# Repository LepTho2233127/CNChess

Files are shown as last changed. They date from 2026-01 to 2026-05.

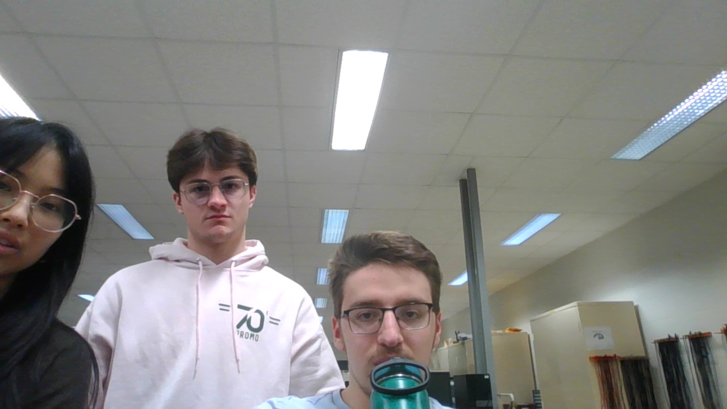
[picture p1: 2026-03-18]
python/best_chess_board.jpg

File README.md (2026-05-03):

# CNChess - Automated Chess System
Automated chess board for playing against chess engine. For more information concerning the hardware needed visit the [wiki](https://github.com/LepTho2233127/CNChess/wiki)
Image (4)

<div align="center">
IMG_8428 (online-video-cutter com) (2)
</div>

## Get Started for Software Development

### 1. Clone project
    git clone <REPO_URL>

### 2. Install Ubuntu WSL (only if on windows)

[Instructions](https://learn.microsoft.com/en-us/windows/wsl/install)

### 3. Open WSL inside project folder

### 4. Install docker

```bash
sudo apt update && sudo apt upgrade
```

[Instructions](https://docs.docker.com/engine/install/ubuntu/)

### 5. If on WSL, give access to USB port to WSL 

```bash
winget install --interactive --exact dorssel.usbipd-win
```

> [!IMPORTANT]
> Run the following commands as admin in PowerShell. You also need to keep a WSL active

```PowerShell
usbipd list
usbipd bind --busid 4-4
usbipd attach --wsl --busid <busid>
```

In WSL, check if you see the device you just attached
```bash
lsusb
```

### 6. Build docker image
```bash
sudo docker compose build
```

### 7. Give docker access to window 
```bash
xhost +local:docker
```

### 8. Run code
```bash
sudo docker compose run cnchess
```

### 9. Close docker (or ctrl-c)
```bash
sudo docker compose down
```
> [!NOTE]
> If you are on a Linux operating systems, it is possible to not use Docker by following this procedure

### 1. Install Stockfish at default location
```bash
sudo apt update
sudo apt install stockfish
which stockfish
```
>[!IMPORTANT]
>If path obtained when running which command is not /usr/games/stockfish, you need to change it in CNChess.py file manually

### 2. Install Python libraries
Inside CNChess directory run : 

```bash
cd python
python -m venv .venv
source .venv/bin/activate
pip install -r requirements.txt
```

### 3. Run the project
With right hardware, run this command in python directory with virtual environment activated
```bash
python main.py
```
If no camera or serial port is detected, you might need to change it respectively inside Cam.py or Communication.py.

## Documentation
Additional software documentation is available and generated using MkDocs [docs](https://leptho2233127.github.io/CNChess/). Run `mkdocs build` inside project directory to build it.
Located inside docs_build directory, open in a browser to access it.

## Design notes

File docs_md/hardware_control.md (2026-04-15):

[← Back to Home](index.md)

# Hardware Control

Robot control systems for movement, positioning, and piece manipulation.

**Related Components:** [Game Engine](game_engine.md) | [Vision System](vision_system.md) | [Communication](communication.md) | [UI](user_interface.md)

## Overview

The Hardware Control component is responsible for:

- **Pathfinding & Trajectory Planning** - Calculate optimal robot paths from as grid coordinates
- **Servo Control** - Manage piece picking and placement

## Key Features

- **Intelligent Pathfinding** - Efficient path calculation avoiding collisions using A* algorithm
- **Servo Management** - Automated piece manipulation with magnet control

## Architecture

```
Hardware Control
├── Pathfinding Engine
│   ├── Start Position
│   ├── Destination Position
│   └── Path Generation
└── Movement Commands
    ├── Grid Positions
    └── Servo Operations
```

## Coordinate Systems

### Chess Board Coordinates
- Columns: A-H (Left to Right)
- Rows: 1-8 (Bottom to Top)
- Example: e4 (King's Pawn opening)

### Grid Coordinates
- Grid double the size of chess board (16x16), so the pieces can be moved in between the squares. (0,0) represents the bottom left corner
- Calibration required to the bottom left corner for accurate mapping

## Usage Example

```python
from Control import Control
import chess

# Initialize control system
control = Control()

# Home the robot
control.go_home()

# Get path for a move
move = chess.Move.from_uci('e2e4')
path = control.get_path(move, board_state)
```

## Module Documentation

### Control Module

The core control system for robot movement and pathfinding.

::: Control
    options:
      docstring_style: google

```

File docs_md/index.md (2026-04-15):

# CNChess Documentation

Welcome to the CNChess documentation! This is an automated chess playing robot that uses computer vision and robotic control to play chess games.

## System Overview

The CNChess system is divided into five main component groups. Each component has its own dedicated documentation page:

### [Game Engine](game_engine.md)
Chess logic and chess engine decision-making. Handles game state, move validation, and opponent strategy.

### [Hardware Control](hardware_control.md)
Robot movement and positioning system. Controls gantry movements, servo operations, and trajectory planning.

### [Vision System](vision_system.md)
Computer vision for board detection. Processes camera input to recognize piece positions and moves.

### [Communication Layer](communication.md)
Device communication protocol. Manages serial communication with ESP32 and hardware control.

### [User Interface](user_interface.md)
PyQt6-based graphical interface. Provides game interaction, settings configuration, and visual feedback.

## System Architecture

```
User Input (Button Press)
    ↓
Camera (Detect Result)
    ↓
Game Engine (Validate Move and Calculates Computer Move)
    ↓
Control Module (Path Planning)
    ↓
Communication (Send to Device)
    ↓
Hardware (Robot Movement)
    ↓
Update Game State (UI Display)
```

## Quick start

### 1. Clone project
    git clone <REPO_URL>

### 2. Install Ubuntu WSL (only if on windows)

[Instructions](https://learn.microsoft.com/en-us/windows/wsl/install)

### 3. Open WSL inside project folder

### 4. Install docker

```bash
sudo apt update && sudo apt upgrade
```

[Instructions](https://docs.docker.com/engine/install/ubuntu/)

### 5. If on WSL, give access to USB port to WSL 

```bash
winget install --interactive --exact dorssel.usbipd-win
```

> [!IMPORTANT]
> Run the following commands as admin in PowerShell. You also need to keep a WSL active

```PowerShell
usbipd list
usbipd bind --busid 4-4
usbipd attach --wsl --busid <busid>
```

In WSL, check if you see the device you just attached
```bash
lsusb
```

### 6. Build docker image
```bash
sudo docker compose build
```

### 7. Give docker access to window 
```bash
xhost +local:docker
```

### 8. Run code
```bash
sudo docker compose run cnchess
```

### 9. Close docker (or ctrl-c)
```bash
sudo docker compose down
```
> [!NOTE]
> If you are on a Linux operating systems, it is possible to not use Docker by following this procedure

### 1. Install Stockfish at default location
```bash
sudo apt update
sudo apt install stockfish
which stockfish
```
>[!IMPORTANT]
>If path obtained when running which command is not /usr/games/stockfish, you need to change it in CNChess.py file manually

### 2. Install Python libraries
Inside CNChess directory run : 

```bash
cd python
python -m venv .venv
source .venv/bin/activate
pip install -r requirements.txt
```

### 3. Run the project
With right hardware, run this command in python directory with virtual environment activated
```bash
python main.py
```
If no camera or serial port is detected, you might need to change it respectively inside Cam.py or Communication.py.

## Documentation
Additional software documentation is available and generated using MkDocs. Run `mkdocs build` inside project directory to build it.
Located inside docs directory, open in a browser to access it.

## System Requirements

- Docker or Python>=3.8
- PyQt6
- OpenCV for vision processing
- PySerial for device communication
- Python chess library for game logic
- Stockfish 14.1 (bundled inside docker)

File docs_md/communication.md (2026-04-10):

[← Back to Home](index.md)

# Communication Layer

Device communication for ESP32 and hardware control via PySerial.

**Related Components:** [Game Engine](game_engine.md) | [Hardware Control](hardware_control.md) | [Vision System](vision_system.md) | [UI](user_interface.md)

## Overview

The Communication Layer component is responsible for:

- **Serial Communication** - Establish connection with microcontroller
- **Protocol Handling** - Encode/decode command messages
- **Command Transmission** - Send movement and control commands
- **Status Monitoring** - Receive and interpret device feedback
- **Error Handling** - Manage communication failures gracefully

## Module Documentation

### Communication Module

The serial communication system for hardware device control.

::: Communication
    options:
      docstring_style: google

## Key Features

- **Robust Serial Protocol** - Reliable communication with error checking
- **Asynchronous Operation** - Non-blocking command transmission
- **Auto-reconnection** - Handle disconnections gracefully
- **Timeout Management** - Prevent hanging on failed commands

## Architecture

```
Communication Layer
├── Serial Port Management
│   ├── Port Detection
│   └── Connection State
├── Command Protocol
│   ├── Command Encoding
│   └── Parameter Packing
├── Response Handling
│   ├── Message Parsing
│   └── Error Detection
└── Device Interface
    ├── Gantry Movement Status
    └── Servo State Feedback
```

## Command Protocol

### Message Format

```
[COMMAND] [PARAMETERS] <>

        1 byte    variable     1 byte    0xFF
```

### Common Commands

- **HOME** - Move gantry to home position
- **MOVE** - Execute X,Y absolute movement command 
- **JOG** - Execute X,Y relative movement command  
- **SERVO** - Control up down of effector to manipulate pieces (magnet)
- **STOP** - Stop gantry 
- **CHESSMOVE** - Send command as grid coordinate with effector state
- **PATH** - Send complete sets of command to execute a complete chess move

## Communication Flow

1. **Initialization** - Detect and connect to device
2. **Handshake** - Verify device is responsive
3. **Command Send** - Transmit movement commands
4. **Status Check** - Wait for completion
5. **Error Handling** - Retry or abort as needed
6. **Disconnection** - Clean shutdown

## Serial Configuration

```python
from Communication import Communication

# Initialize communicator
comm = Communication()

# Send command
comm.send_path(path_commands)

# Wait for button press (human move)
comm.wait_for_button_press()

```
## Dependencies

- `PySerial` - Serial port communication
- Microcontroller firmware (ESP32/Arduino)

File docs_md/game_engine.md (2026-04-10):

[← Back to Home](index.md)

# Game Engine

The core game engine that handles game logic, move validation, and the chess engine decision-making.

**Related Components:** [Hardware Control](hardware_control.md) | [Vision System](vision_system.md) | [Communication](communication.md) | [UI](user_interface.md)

## Overview

The Game Engine component is responsible for:

- **Game State Management** - Maintaining board positions and game history
- **Move Validation** - Ensuring all moves follow chess rules
- **Chess engine Decision Making** - Generating computer player moves
- **Game Outcome Detection** - Detecting checkmate, stalemate, and draw conditions
- **Choosing difficulty level** - Easy, medium or hard

## Module Documentation

### Main Entry Point

The main application entry point that initializes the entire system.

::: main
    options:
      docstring_style: google

### Chess Game Engine

The core chess game logic and state management system. It uses python `chess` library and Stockfish chess engine at various difficulties.

::: CNChess
    options:
      docstring_style: google

## Key Features

- **FEN Support** - Full Forsyth-Edwards Notation support for board representation
- **Move Legality** - Complete validation of chess move rules
- **Game History** - Track all moves with ability to undo/redo
- **Chess engine Opponent** - Computer player with configurable difficulty (easy, medium or hard)
- **Promotion Handling** - Automatic pawn promotion on reach of last rank
- **Check/Checkmate Detection** - Real-time detection of game-ending conditions

## Architecture

```
Game Engine
├── Board State (FEN)
├── Move Validation
│   ├── Legal Moves Generator
│   ├── Rule Enforcement
│   └── Special Moves (Castling, En Passant, Promotion)
├── Chess Engine Decision Making
└── Game Outcome
    ├── Checkmate Detection
    └── Draw Detection
```

## Usage Example

```python
from CNChess import CNChess

# Initialize the game
chess_game = CNChess()

# Get current board state
board_state = chess_game.get_board_state()

# Get legal moves for a piece
legal_moves = chess_game.get_legal_moves_from_square('e2')

# Validate and make a move
move = chess.Move.from_uci('e2e4')
if chess_game.validate_move(move):
    chess_game.make_move(move)

# Get chess engine move
best_move = chess_game.get_next_best_move()
```

## Dependencies

- `chess` - Python chess library for game logic
- `Python 3.8+` - Core language

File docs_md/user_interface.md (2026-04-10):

[← Back to Home](index.md)

# User Interface

PyQt6-based graphical interface for game interaction and configuration.

**Related Components:** [Game Engine](game_engine.md) | [Hardware Control](hardware_control.md) | [Vision System](vision_system.md) | [Communication](communication.md)

## Overview

The User Interface component is responsible for:

- **Game Visualization** - Display board state and piece positions
- **User Interaction** - Handle move input and game control
- **Settings Management** - Configure system parameters
- **Visual Feedback** - Show status, timers, and notifications
- **Navigation** - Switch between game, settings, and home screens

## Game Flow

```
Home Page (Game Mode Selection)
    ↓
Game Page (Play Chess)
    ├─ Human Move Detection
    ├─ Chess Engine Move Generation
    └─ Board Update/Display
    ↓
End Game Dialog (Result)
    ├─ Play Again → Home Page
    └─ Exit → Application Close
```

## Navigation Structure

```
Main Application
├── Home Page
│   ├── Difficulty Choice
│   ├── Color Choice
│   └── Settings Button
├── Game Page
│   ├── Chess Board
│   ├── Move History
│   ├── Chess Clocks
│   ├── Settings Button (Context)
│   ├── Undo Button
│   └── Resign Button
├── Settings Page
│   ├── Core XY Control
│   ├── Camera Calibration and Control
│   └── Magnet Control
└── Dialogs
    ├── Game Over (Win/Draw/Loss)
    ├── Invalid Move Warning
    ├── Promotion Selection
    └── Waiting Indicator
```

## Key Features

- **Responsive Design** - Adapts to different screen sizes
- **Drag & Drop Moves** - Click pieces and drag to destination
- **Keyboard Shortcuts** - Quick access to common functions
- **Undo/Redo** - Review and navigate game history
- **Settings Persistence** - Save preferences between sessions
- **Error Messages** - Clear feedback for user actions
- **Accessible Controls** - Large buttons and readable fonts

## Styling

The interface uses Material Design theme with custom stylesheet (`cnchess_theme.qss`) for consistent visual appearance.

## Usage Example

```python
from main_ui import MainWindow
from PyQt6.QtWidgets import QApplication
import sys

# Create application
app = QApplication(sys.argv)

# Create main window
window = MainWindow()
window.show()

# Run application
sys.exit(app.exec())
```

## Dependencies

- `PyQt6` - GUI framework
- `PyQt6.QtCore` - Core Qt functionality
- `PyQt6.QtGui` - Graphics and icons
- `PyQt6.QtWidgets` - Widget components
- Custom stylesheets (QSS files)

## Module Documentation

### Main UI Application

The primary application window and navigation system.

::: ui.main_ui
    options:
      docstring_style: google

### Game Page

The main game interface where chess is played.

::: ui.game_page
    options:
      docstring_style: google

### Home Page

The home/welcome screen and game mode selection.

::: ui.home_page
    options:
      docstring_style: google

### Settings Page

Configuration interface for system settings and calibration.

::: ui.settings_page
    options:
      docstring_style: google

### Dialog Components

Popup dialogs for notifications and selections.

::: ui.dialog_ui
    options:
      docstring_style: google

## User Interface Components

### Game Board
- **Visual Representation** - 8x8 chess board with pieces
- **Square Highlighting** - Show selected piece and legal moves
- **Trajectory Display** - Show robot movement path

### Move History
- **Notation List** - Display all moves in algebraic notation
- **Move Navigation** - Step backward/forward through game
- **Capture Indicators** - Mark captured pieces

### Chess Clock
- **Time Display** - Show remaining time for each player
- **Color Indicators** - White/black background for current player
- **Out of Time Detection** - Automatic game end on timeout

### Status Indicators
- **Turn Indicator** - Show which player's turn it is
- **Waiting Spinner** - Show processing status with animated gear
- **Error Messages** - Display issues or invalid moves

### Settings Controls
- **Board Orientation** - Rotate board perspective (possible to play as black or white)
- **Difficulty Selection** - Choose chess engine opponent strength
- **Device Configuration** - Select and test hardware (core XY or camera)

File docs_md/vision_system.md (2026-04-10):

[← Back to Home](index.md)

# Vision System

Computer vision for board detection and piece position recognition.

**Related Components:** [Game Engine](game_engine.md) | [Hardware Control](hardware_control.md) | [Communication](communication.md) | [UI](user_interface.md)

## Overview

The Vision System component is responsible for:

- **Image Capture** - Retrieve frames from camera
- **Board Detection** - Identify chess board boundaries and orientation
- **Piece Recognition** - Locate individual pieces and their positions
- **Move Detection** - Determine what move was made from before/after images
- **Optical Validation** - Verify game state matches expectations

## Module Documentation

### Camera Module

The computer vision system for board and piece detection.

::: Cam
    options:
      docstring_style: google

## Key Features

- **Real-time Processing** - Fast image analysis for smooth gameplay
- **Piece Classification** - Identify piece type and color
- **Board Orientation** - Automatic detection of board perspective
- **Lighting Adaptation** - Handle varying lighting conditions
- **Calibration Support** - Customizable calibration points for accuracy
- **Move Validation** - Verify moves match detected piece movements

## Architecture

```
Vision System
├── Camera Interface
│   ├── Frame Capture
│   ├── Resolution: 1280x960
│   └── Stabilization
├── Board Detection
│   ├── Edge Detection
│   ├── Board Boundaries
│   └── Square Identification
├── Piece Recognition
│   ├── Color Detection
│   ├── Piece Type Classification
│   └── Position Mapping
└── Move Analysis
    ├── Before/After Comparison
    ├── Piece Movement Tracking
    └── FEN Generation
```

## Image Processing Pipeline

1. **Capture** - Get frame from camera
2. **Preprocessing** - Apply color correction and normalization
3. **Board Detection** - Identify board grid and squares
4. **Piece Segmentation** - Extract individual pieces from squares
5. **Classification** - Determine piece type and color
6. **Position Mapping** - Convert pixel coordinates to chess notation
7. **Move Detection** - Compare with previous board state

## Calibration

The system requires calibration points for accurate position mapping:

```python
from Cam import Cam

# Initialize camera
cam = Cam()

# Calibration points format
# Maps chess board positions to pixel coordinates
calibration_points = {
    'a1': (x1, y1),
    'a8': (x2, y2),
    'h1': (x3, y3),
    'h8': (x4, y4),
    # ... additional calibration points
}
```

## Lighting Requirements

- **Optimal Lighting** - Uniform, consistent lighting across board
- **Avoid Glare** - Position camera to minimize reflections
- **Shadow Reduction** - Maintain even illumination
- **Color Accuracy** - Calibrate white balance for piece detection

## Usage Example

```python
from Cam import Cam

# Initialize camera
cam = Cam()

# Capture and process image
result = cam.process_image()

# Result contains:
# - Board state (FEN)
# - Detected move (UCI notation)
# - Confidence score
# - Raw image data

print(f"Detected move: {result['move']['uci']}")
print(f"Board state: {result['board_state']}")
```

## Dependencies

- `OpenCV` - Computer vision processing
- `NumPy` - Image manipulation
- `Camera hardware` - USB or integrated camera
- Calibration data file

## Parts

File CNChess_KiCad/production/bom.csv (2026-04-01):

Designator | Footprint | Quantity | Value | LCSC Part #
C1, C2 | CAP0_1u | 2 | 0.1uF
C3, C4 | CP_Radial_D10.0mm_P5.00mm | 2 | 1000uF
D1 | JST_XH_B2B-XH-A_1x02_P2.50mm_Vertical | 1 | 12V LED
D2 | JST_XH_B2B-XH-A_1x02_P2.50mm_Vertical | 1 | 3V3 LED
D3 | JST_XH_B2B-XH-A_1x02_P2.50mm_Vertical | 1 | X
D4 | JST_XH_B2B-XH-A_1x02_P2.50mm_Vertical | 1 | Y
J1 | BarrelJack_Horizontal | 1 | Barrel_Jack
J2 | JST_XH_B4B-XH-A_1x04_P2.50mm_Vertical | 1 | Motor1
J3 | JST_XH_B4B-XH-A_1x04_P2.50mm_Vertical | 1 | Motor2
J4 | JST_XH_B3B-XH-A_1x03_P2.50mm_Vertical | 1 | Servomotor
J5 | JST_XH_B2B-XH-A_1x02_P2.50mm_Vertical | 1 | Fan
R1 | R_Axial_DIN0204_L3.6mm_D1.6mm_P5.08mm_Horizontal | 1 | 1000
R2, R3, R5 | R_Axial_DIN0204_L3.6mm_D1.6mm_P5.08mm_Horizontal | 3 | 270
R4, R6 | R_Axial_DIN0204_L3.6mm_D1.6mm_P5.08mm_Horizontal | 2 | 47k
SW1 | JST_XH_B2B-XH-A_1x02_P2.50mm_Vertical | 1 | LSW1
SW2 | JST_XH_B2B-XH-A_1x02_P2.50mm_Vertical | 1 | LSW2
SW3 | JST_XH_B2B-XH-A_1x02_P2.50mm_Vertical | 1 | OOSW
TMC1, TMC2 | TMC2209 | 2 | Driver
TP1 | TestPoint_Pad_D1.5mm | 1 | TP12V
TP2 | TestPoint_Pad_D1.5mm | 1 | TP5V
TP3 | TestPoint_Pad_D1.5mm | 1 | TPSW1
TP4 | TestPoint_Pad_D1.5mm | 1 | TPSW2
U1 | Esp32-C3 | 1 | ESP32C3
U2 | Reg_12V | 1 | Power_Regulator

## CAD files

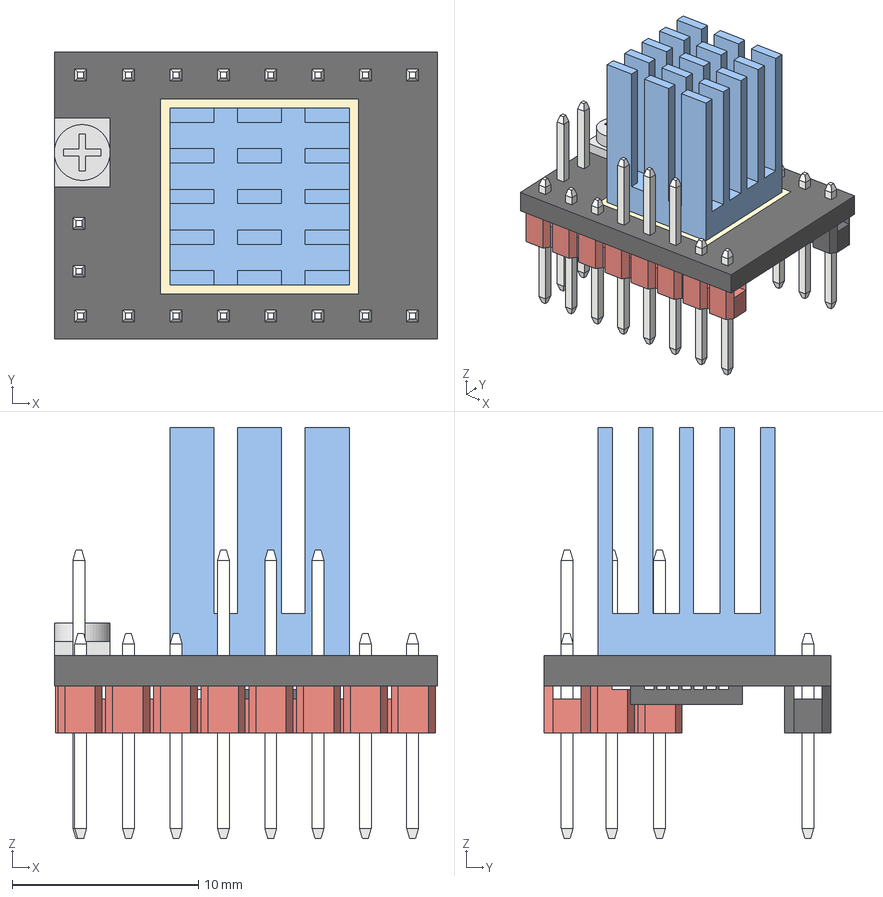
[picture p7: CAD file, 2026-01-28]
CNChess_KiCad/3d_models/BTT TMC2208 TMC2209 UART Stepper Driver.step
20.6 x 15.4 x 22.1 mm
8 Pin Header v0
8 Pin Header v0(Mirror)
PCB

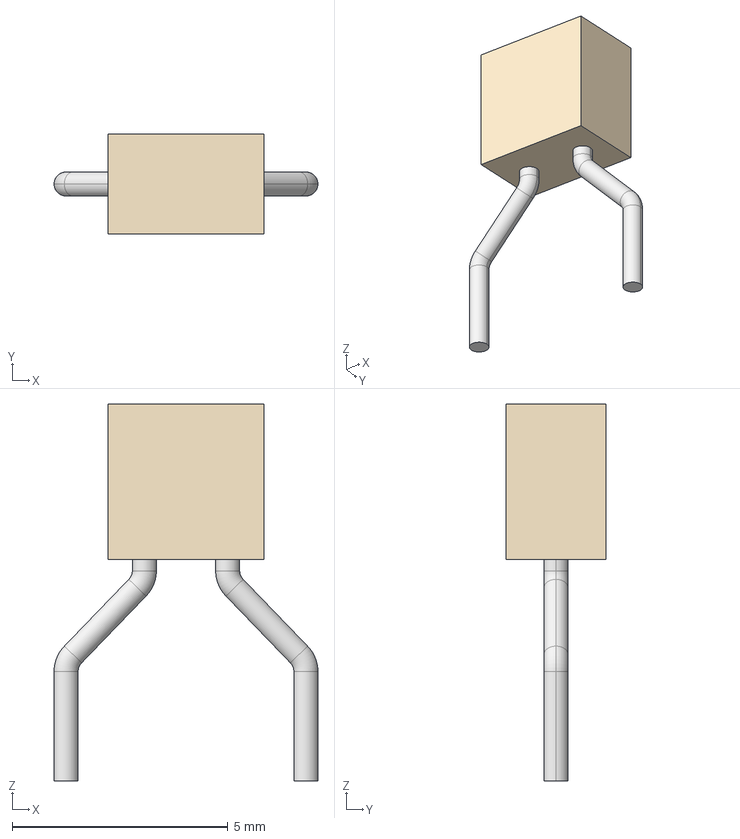
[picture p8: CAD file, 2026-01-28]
CNChess_KiCad/3d_models/K104K10X7RF5UH5_VIS.step
6.12 x 2.31 x 8.74 mm

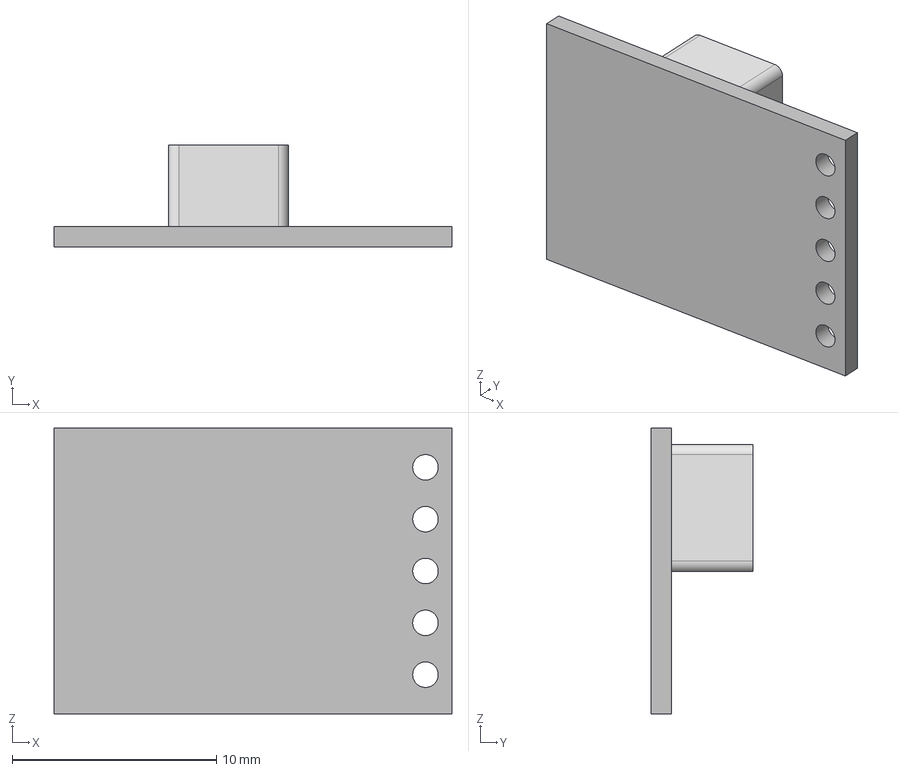
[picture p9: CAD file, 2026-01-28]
CNChess_KiCad/3d_models/F_reg_12v.step
19.5 x 5.00 x 14.0 mm

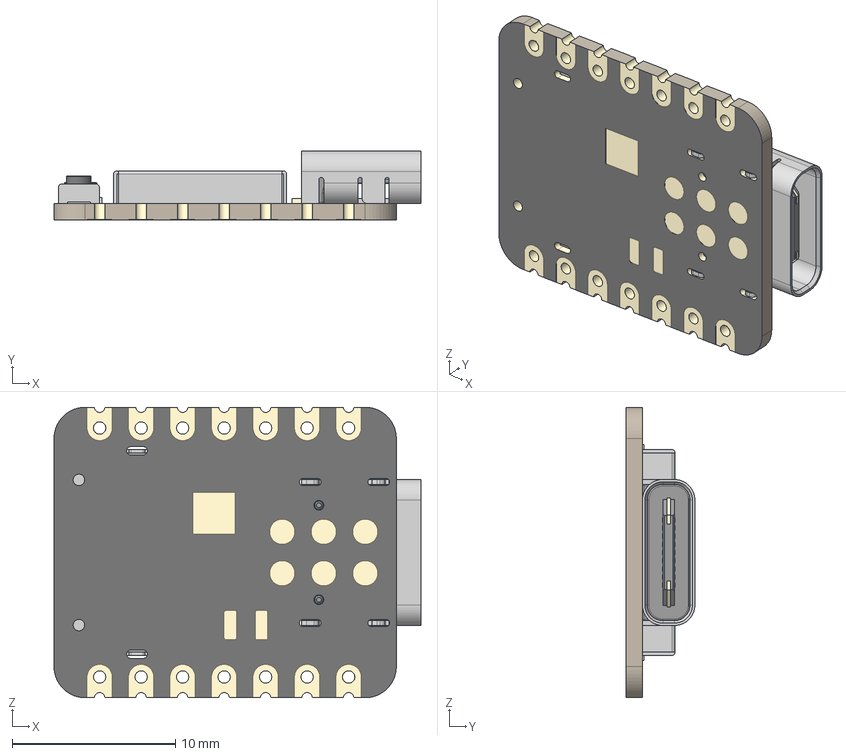
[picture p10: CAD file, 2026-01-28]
CNChess_KiCad/3d_models/Seeed Studio XIAO-ESP32-C3.step
22.5 x 4.21 x 17.8 mm
BOSS-EXTRUDE14_8_
BOSS-EXTRUDE7_4_
BOSS-EXTRUDE7_3_
BOSS-EXTRUDE14_4_
BOSS-EXTRUDE14_2_
BOSS-EXTRUDE14_11_
BOSS-EXTRUDE7_7_
BOSS-EXTRUDE14_9_
BOSS-EXTRUDE14_3_
BOSS-EXTRUDE14_7_
MIRROR2
BOSS-EXTRUDE14_5_
BOSS-EXTRUDE14_12_
BOSS-EXTRUDE7_8_
BOSS-EXTRUDE7_1_
BOSS-EXTRUDE14_10_
BOSS-EXTRUDE7_9_
BOSS-EXTRUDE14_6_
BOSS-EXTRUDE14_1_
BOSS-EXTRUDE7_6_
BOSS-EXTRUDE7_2_
CUT-EXTRUDE5
BOSS-EXTRUDE7_5_
U.FL Connector v1
Button (1) x 2
Shield

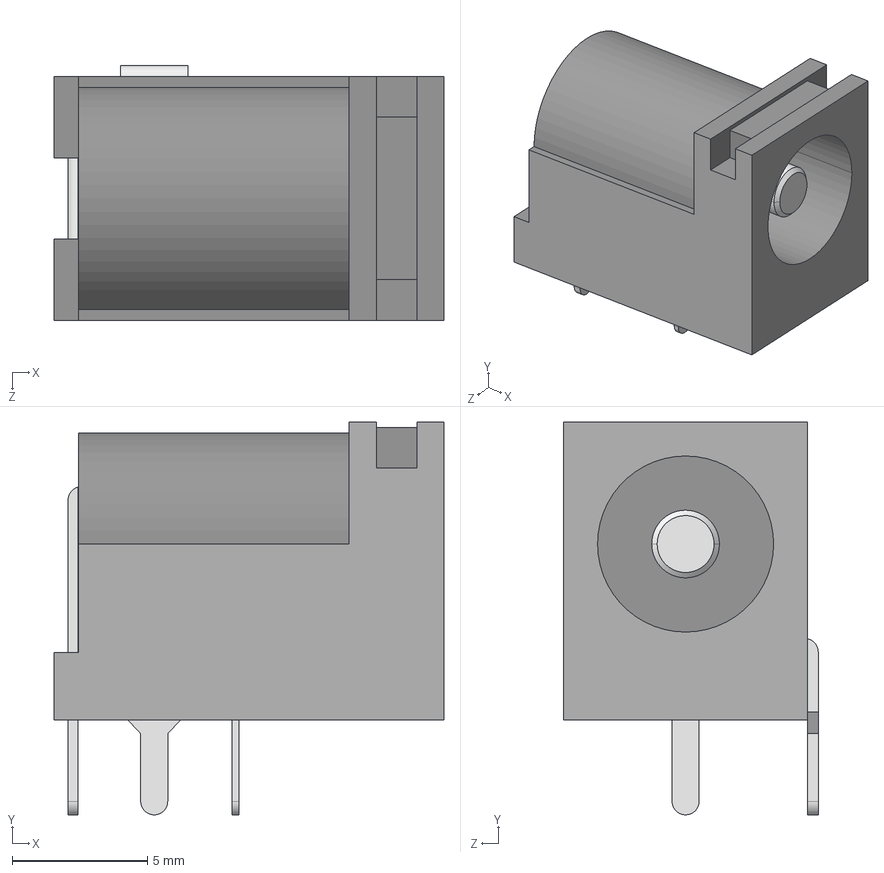
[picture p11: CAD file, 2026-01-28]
CNChess_KiCad/3d_models/PJ-102BH.step
14.4 x 14.5 x 9.40 mm

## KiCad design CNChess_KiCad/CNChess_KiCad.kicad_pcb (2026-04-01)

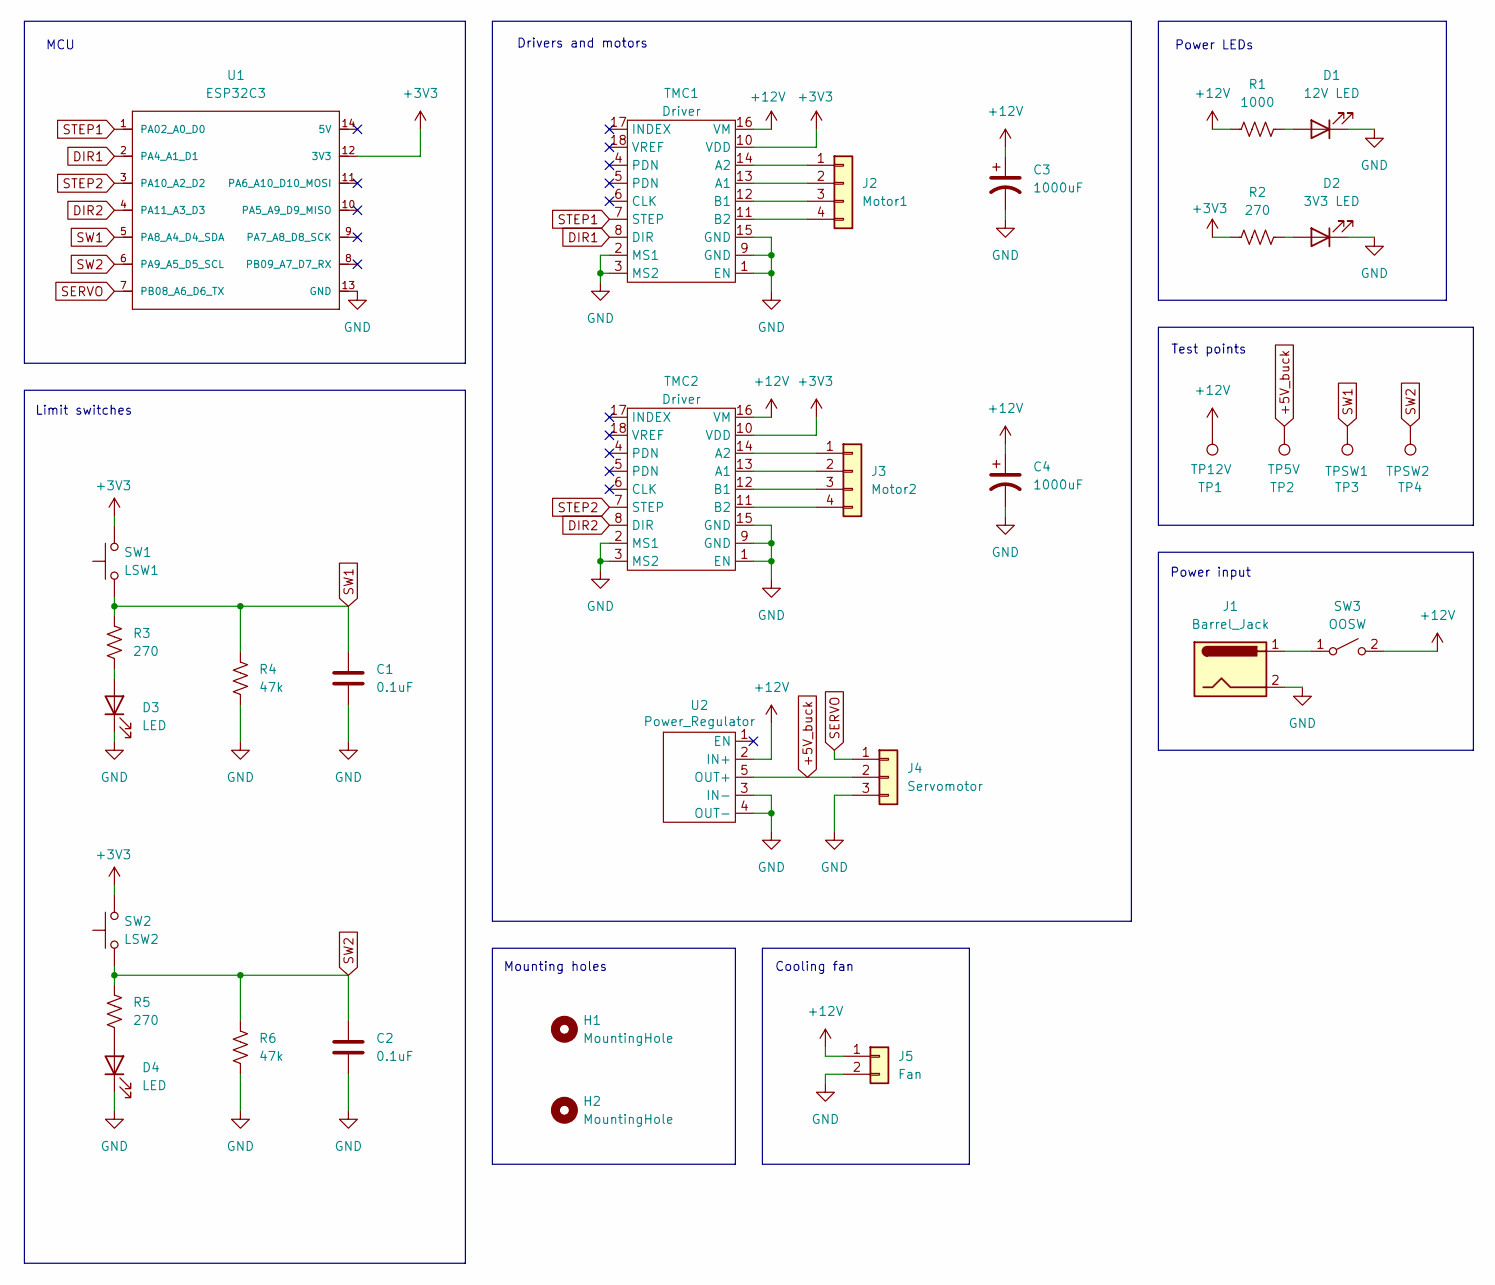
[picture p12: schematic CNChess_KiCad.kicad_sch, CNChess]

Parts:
C1, C2: 0.1uF; CAP0_1u
C3, C4: 1000uF; CP_Radial_D10.0mm_P5.00mm
D1: 12V LED; JST_XH_B2B-XH-A_1x02_P2.50mm_Vertical
D2: 3V3 LED; JST_XH_B2B-XH-A_1x02_P2.50mm_Vertical
D3, D4: LED; JST_XH_B2B-XH-A_1x02_P2.50mm_Vertical
H1, H2: MountingHole; MountingHole_3.2mm_M3_Pad
J1: Barrel_Jack; BarrelJack_Horizontal
J2: Motor1; JST_XH_B4B-XH-A_1x04_P2.50mm_Vertical
J3: Motor2; JST_XH_B4B-XH-A_1x04_P2.50mm_Vertical
J4: Servomotor; JST_XH_B3B-XH-A_1x03_P2.50mm_Vertical
J5: Fan; JST_XH_B2B-XH-A_1x02_P2.50mm_Vertical
R1: 1000; R_Axial_DIN0204_L3.6mm_D1.6mm_P5.08mm_Horizontal
R2, R3, R5: 270; R_Axial_DIN0204_L3.6mm_D1.6mm_P5.08mm_Horizontal
R4, R6: 47k; R_Axial_DIN0204_L3.6mm_D1.6mm_P5.08mm_Horizontal
SW1: LSW1; JST_XH_B2B-XH-A_1x02_P2.50mm_Vertical
SW2: LSW2; JST_XH_B2B-XH-A_1x02_P2.50mm_Vertical
SW3: OOSW; JST_XH_B2B-XH-A_1x02_P2.50mm_Vertical
TMC1, TMC2: Driver; TMC2209
TP1: TP12V; TestPoint_Pad_D1.5mm
TP2: TP5V; TestPoint_Pad_D1.5mm
TP3: TPSW1; TestPoint_Pad_D1.5mm
TP4: TPSW2; TestPoint_Pad_D1.5mm
U1: ESP32C3; Esp32-C3
U2: Power_Regulator; Reg_12V

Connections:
+3V3: R2.1, SW1.2, SW2.2, TMC1.10 (VDD), TMC2.10 (VDD), U1.12 (3V3)
+5V_buck: J4.2, TP2.1, U2.5 (OUT+)
+12V: C3.1, C4.1, J5.1, R1.1, SW3.2 (B), TMC1.16 (VM), TMC2.16 (VM), TP1.1, U2.2 (IN+)
DIR1: TMC1.8 (DIR), U1.2 (PA4_A1_D1)
DIR2: TMC2.8 (DIR), U1.4 (PA11_A3_D3)
GND: C1.2, C2.2, C3.2, C4.2, D1.1 (K), D2.1 (K), D3.1 (K), D4.1 (K), J1.2, J4.3, J5.2, R4.1, R6.1, TMC1.1 (EN), TMC1.2 (MS1), TMC1.3 (MS2), TMC1.9 (GND), TMC1.15 (GND), TMC2.1 (EN), TMC2.2 (MS1), TMC2.3 (MS2), TMC2.9 (GND), TMC2.15 (GND), U1.13 (GND), U2.3 (IN-), U2.4 (OUT-)
unnamed: D1.2 (A), R1.2
unnamed: D2.2 (A), R2.2
unnamed: D3.2 (A), R3.1
unnamed: D4.2 (A), R5.1
unnamed: J2.1, TMC1.14 (A2)
unnamed: J2.2, TMC1.13 (A1)
unnamed: J2.3, TMC1.12 (B1)
unnamed: J2.4, TMC1.11 (B2)
unnamed: J3.1, TMC2.14 (A2)
unnamed: J3.2, TMC2.13 (A1)
unnamed: J3.3, TMC2.12 (B1)
unnamed: J3.4, TMC2.11 (B2)
unnamed: J1.1, SW3.1 (A)
SERVO: J4.1, U1.7 (PB08_A6_D6_TX)
STEP1: TMC1.7 (STEP), U1.1 (PA02_A0_D0)
STEP2: TMC2.7 (STEP), U1.3 (PA10_A2_D2)
SW1: C1.1, R3.2, R4.2, SW1.1, TP3.1, U1.5 (PA8_A4_D4_SDA)
SW2: C2.1, R5.2, R6.2, SW2.1, TP4.1, U1.6 (PA9_A5_D5_SCL)

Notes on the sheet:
Limit switches
Mounting holes
Drivers and motors
Cooling fan
Test points
MCU
Power LEDs
Power input

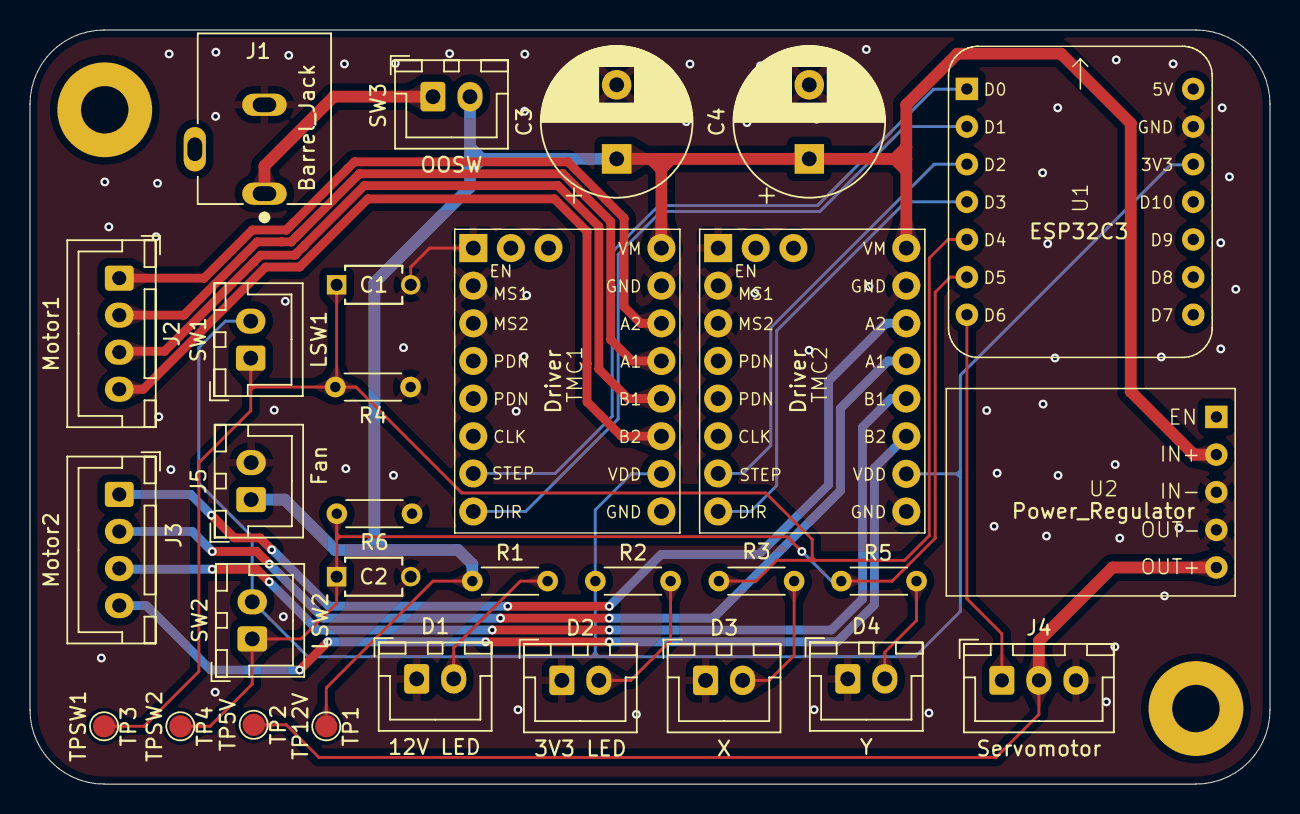
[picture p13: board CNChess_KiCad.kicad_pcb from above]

Board: 2 copper layers, 83.7 x 50.9 mm, 32 parts (0 on the bottom side), 24 nets.

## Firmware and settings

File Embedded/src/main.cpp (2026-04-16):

#include "AccelStepper.h"
#include "MultiStepper.h"
#include <Arduino.h>
#include <math.h>
#include <utility>
#include <Servo.h>
#include <string>
#include <vector>
#include <sstream>

#define SQUARE_SIZE_MM 50.8  // Size of a chess square in millimeters
#define STEP_ANGLE_DEGREES 1.8  // Stepper motor step angle in degrees
#define PULLEY_DIAMETER 12.0  // Pulley diameter in millimeters
#define CIRCUMFERENCE (PULLEY_DIAMETER * PI)
#define MICROSTEPPING 8.0
#define DEADZONE_MM 24  // Deadzone in millimeters for movement commands

#define STEP_PIN_1 D0
#define DIR_PIN_1 D1
#define STEP_PIN_2 D2
#define DIR_PIN_2 D3
#define PLAY_PIN D7

#define SERVO_PIN D6
#define LED_PIN D8

#define LIMIT_SWITCH_1 D4
#define LIMIT_SWITCH_2 D5

#define HOME_SPEED 4000
#define MOVE_SPEED 4000  

AccelStepper stepper1(AccelStepper::DRIVER, STEP_PIN_1, DIR_PIN_1); // step, dir pins
AccelStepper stepper2(AccelStepper::DRIVER, STEP_PIN_2, DIR_PIN_2); // step, dir pins
MultiStepper steppers;

int servoGrabPosition = 52; // Servo position to grab piece0
int servoReleasePosition = 130; // Servo position to release piece
bool button_pressed = false;

struct Position{
    float x;
    float y;
};

Position current_position;
Position drop_position = {0.5, 5.5};

std::pair<float, float> get_steps(float delta_x, float delta_y);

void IRAM_ATTR onPlayButtonPress() {
    // This function will be called when the play button is pressed
    button_pressed = true;
}

void go_to_position (Position pos);
void go_home();
void reset_position();
void grab_piece(bool state);
void release_piece(bool state);
void move_distance(float delta_x, float delta_y);
void drop_piece();

Servo myServo;

void setup() {

    Serial.begin(115200);

    // Initialize pins
    pinMode(LIMIT_SWITCH_1, INPUT);
    pinMode(LIMIT_SWITCH_2, INPUT);
    pinMode(LED_PIN, OUTPUT);
    pinMode(SERVO_PIN, OUTPUT);
    pinMode(PLAY_PIN, INPUT_PULLDOWN);
    
    // Configure stepper motors
    stepper1.setMaxSpeed(MOVE_SPEED);
    stepper1.setAcceleration(500);
    stepper2.setMaxSpeed(MOVE_SPEED);
    stepper2.setAcceleration(500);
    steppers.addStepper(stepper1);
    steppers.addStepper(stepper2);

    attachInterrupt(PLAY_PIN, onPlayButtonPress, RISING);
    myServo.attach(SERVO_PIN);
    go_home();
    myServo.write(servoReleasePosition); // Ensure servo is in release position
}

// Define the command types
enum CommandType {
    CHESSMOVE,
    MOVE,
    HOME,
    JOG,
    STOP,
    PATH,
    SERVO
};

// Function to parse command type from string
CommandType parseCommand(String cmd) {
    if (cmd == "CHESSMOVE") return CHESSMOVE;
    if (cmd == "MOVE") return MOVE;
    if (cmd == "HOME") return HOME;
    if (cmd == "STOP") return STOP;
    if (cmd == "JOG")  return JOG;
    if (cmd == "PATH")  return PATH;
    if(cmd == "SERVO") return SERVO;

    return STOP;
}

// Helper function to extract command (uppercase letters at start)
String extractCommand(String input) {
    String cmd = "";
    for (int i = 0; i < input.length(); i++) {
        char c = input[i];
        if (c >= 'A' && c <= 'Z') {
            cmd += c;
        } else {
            break;
        }
    }
    return cmd;
}

// Helper function to parse coordinate data from pipe-separated format
// Format: "|x,y,magnet" or "x,y,magnet"
bool parseCoordinates(String data, float& x, float& y, bool& magnet) {
    // Remove leading '|' if present
    if (data[0] == '|') {
        data = data.substring(1);
    }
    
    int firstComma = data.indexOf(',');
    int secondComma = data.indexOf(',', firstComma + 1);
    
    if (firstComma == -1 || secondComma == -1) {
        return false;
    }
    
    x = data.substring(0, firstComma).toFloat();
    y = data.substring(firstComma + 1, secondComma).toFloat();
    magnet = data.substring(secondComma + 1).toInt() != 0;
    
    return true;
}

Position parsePosition(String data) {
    // Remove leading '|' if present
    if (data.length() > 0 && data[0] == '|') {
        data = data.substring(1);
    }
    
    // Parse pipe-separated format: "x|y"
    int pipeIndex = data.indexOf('|');
    if (pipeIndex == -1) {
        return {0, 0}; // Invalid format
    }
    
    float x = data.substring(0, pipeIndex).toFloat();
    float y = data.substring(pipeIndex + 1).toFloat();

    return {x, y};
}

// Helper function to parse PATH command with multiple coordinate sets
std::vector<std::string> splitByPipe(String input) {
    std::vector<std::string> result;
    int start = 0;
    
    for (int i = 0; i <= input.length(); i++) {
        if (i == input.length() || input[i] == '|') {
            if (i > start) {
                String segment = input.substring(start, i);
                result.push_back(std::string(segment.c_str()));
            }
            start = i + 1;
        }
    }
    
    return result;
}

void loop() {

    // Check if play button was pressed
    if (button_pressed){
        Serial.println("PLAYED");
        button_pressed = false;
    }

    // Check for incoming serial commands
    if (Serial.available() > 0) 
    {
        String input = Serial.readStringUntil('\n');
        input.trim();

        // Extract command (uppercase letters at start)
        String commandString = extractCommand(input);
        CommandType commandType = parseCommand(commandString);
        String dataString = input.substring(commandString.length());

        float posX = current_position.x;
        float posY = current_position.y;
        bool magnetState = false;
        
        // Handle commands based on type
        switch (commandType) 
        {
            case CommandType::PATH: {
                // Parse format: "PATH|x,y,magnet|x,y,magnet|..."
                std::vector<std::string> segments = splitByPipe(input.substring(4)); // Skip "PATH"
                
                for (const auto& segment : segments) {
                    if (segment.empty()) continue;
                    
                    String segStr(segment.c_str());
                    if (parseCoordinates(segStr, posX, posY, magnetState)) {
                        posX = posX * SQUARE_SIZE_MM;
                        posY = posY * SQUARE_SIZE_MM;
                        go_to_position({posX, posY});
                        if ((abs(posX - drop_position.x*SQUARE_SIZE_MM)) < 0.01 && (abs(posY - drop_position.y*SQUARE_SIZE_MM)) < 0.01) {
                            drop_piece();
                        }
                        grab_piece(magnetState);
                        digitalWrite(LED_PIN, magnetState);
                    }
                }
                Serial.println("DONE");
                break;
            }
            // CHESSMOVE works using grid positions (0-7) and magnet state, while MOVE and JOG work using absolute or relative distances in mm
            case CommandType::CHESSMOVE: {
                // Parse format: "CHESSMOVE x,y,magnet"
                String dataStr = input.substring(9); // Skip "CHESSMOVE"
                if (parseCoordinates(dataStr, posX, posY, magnetState)) {
                    posX = posX * SQUARE_SIZE_MM;
                    posY = posY * SQUARE_SIZE_MM;

                    go_to_position({posX, posY});
                    if ((posX == drop_position.x*SQUARE_SIZE_MM) && (posY == drop_position.y*SQUARE_SIZE_MM)) {
                        drop_piece();
                    }
                    grab_piece(magnetState);
                    digitalWrite(LED_PIN, magnetState);
                }
                Serial.println("DONE");
                break;
            }

            case CommandType::MOVE:
                Position targetPos; 
                targetPos = parsePosition(dataString);
                go_to_position({targetPos.x, targetPos.y});
                Serial.println("DONE");
                break;    

            case CommandType::JOG:
                Position deltaPos;
                deltaPos = parsePosition(dataString);
                move_distance(deltaPos.x, deltaPos.y);
                Serial.println("DONE");
                break;
        
            case CommandType::HOME:
                grab_piece(false);
                go_home();
                Serial.println("HOMED");
                break;

            case CommandType::STOP:
                grab_piece(false);
                stepper1.stop();
                stepper2.stop();
                Serial.println("STOPPED");
                break;
            
            case CommandType::SERVO:
                // Get magnet state from input
                magnetState = input.substring(6).toInt() != 0;
                grab_piece(magnetState);
                Serial.println("SERVO");
                break;
        }
    }
}
// Reset the current position to the bottom left corner of the board (0.5, 0.5) in grid coordinates
void reset_position() {
    stepper1.setCurrentPosition(0);
    stepper2.setCurrentPosition(0);
    current_position = {0.5*SQUARE_SIZE_MM, 0.5*SQUARE_SIZE_MM+5}; 
}

// Function to control the servo for grabbing and releasing pieces
void grab_piece(bool state) {
    // Activate magnet to grab piece
    static bool last_state = false;
    if (state == last_state) return;
    last_state = state;
    if (state) {
        myServo.write(servoGrabPosition);
    } else {
        myServo.write(servoReleasePosition);
    }
    delay(250); // Small delay to ensure magnet state change
}

std::pair<float, float> get_steps(float delta_x, float delta_y) {
    // Calculate the number of steps needed for each axis based on the desired movement in mm
    float rot_step1 = -360.0 * (delta_x + delta_y) / (CIRCUMFERENCE * sqrt(2));
    float rot_step2 = -((2*delta_x * 360/(CIRCUMFERENCE * sqrt(2))) + rot_step1);
    float step_mot1 = (rot_step1 * MICROSTEPPING * 1.333) / (STEP_ANGLE_DEGREES);
    float step_mot2 = (rot_step2 * MICROSTEPPING * 1.333)/ (STEP_ANGLE_DEGREES);
    
    return std::make_pair(-step_mot1, -step_mot2);
}

//This fonction move the head of the core XY to an absolute position
void go_to_position (Position pos) { 

    float delta_x = -(pos.x - current_position.x);
    float delta_y = pos.y - current_position.y;
    std::pair<float, float> steps = get_steps(delta_x, delta_y);
    long positions[2];
    positions[0] = static_cast<long>(steps.first) + stepper1.currentPosition();
    positions[1] = static_cast<long>(steps.second) + stepper2.currentPosition();
    steppers.moveTo(positions);
    steppers.runSpeedToPosition();
    current_position = pos; 
}

//This fonction move the head of the core XY by a relative distance
void move_distance(float delta_x, float delta_y) {
    std::pair<float, float> steps = get_steps(-delta_x, delta_y);
    long positions[2];
    positions[0] = static_cast<long>(steps.first);
    positions[1] = static_cast<long>(steps.second);
    stepper1.move(positions[0]);
    stepper2.move(positions[1]);
    while (stepper1.isRunning() || stepper2.isRunning()) {
        stepper1.run();
        stepper2.run();
    }
    current_position.x += delta_x;
    current_position.y += delta_y;
}

void go_home() {

    myServo.write(servoReleasePosition); // Ensure servo is in release position
    while(digitalRead(LIMIT_SWITCH_2) == LOW) 
    {
        stepper1.setSpeed(-HOME_SPEED); // Move towards home
        stepper2.setSpeed(HOME_SPEED); // Move towards home
        stepper1.run();
        stepper2.run();
    }

    stepper1.stop();
    stepper2.stop();
    move_distance(0.0, 2.0); // Move away from limit switches

    while(digitalRead(LIMIT_SWITCH_1) == LOW)
    {
        stepper1.setSpeed(HOME_SPEED); // Move towards home
        stepper2.setSpeed(HOME_SPEED); // Move towards home
        stepper1.run();
        stepper2.run();
    }
    stepper1.stop();
    stepper2.stop();
    move_distance((SQUARE_SIZE_MM/2-2), 0.0); // Move away from limit switches
    reset_position();
}

// Drop sequence when a piece is captured and needs to be dropped in the chute. This is a predefined sequence.
void drop_piece() {
    go_to_position({0.5*SQUARE_SIZE_MM - 1, SQUARE_SIZE_MM*5.5-3});
    go_to_position({1, SQUARE_SIZE_MM*5.5+6});
    go_to_position({1, SQUARE_SIZE_MM*4.5+6});
}

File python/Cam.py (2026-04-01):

import cv2
import numpy as np
import json
import ctypes
import chess
import time
import os

"""Camera pipeline for board calibration, perspective warp, piece detection, and move detection."""

class ImageCalibration:
    """Handle manual board-corner calibration from an image source."""
    
    def __init__(self, image_path: str, scale: float = 1.0):
        """Initialize calibration with image path and scale factor.
        
        Args:
            image_path (str): Path to calibration image file.
            scale (float): Scale factor for image display (default 1.0).
        
        Return:
            None
        """
        self.image_path = image_path
        self.scale = scale
        self.points = []
        self.calibration_file = 'calibration_points.json'
        
    def mouse_click(self, event, x, y, flags, param):
        """Store clicked board-corner points.

        Args:
            event: OpenCV mouse event code.
            x: Mouse x-coordinate in displayed image space.
            y: Mouse y-coordinate in displayed image space.
            flags: OpenCV mouse flags (unused).
            param: Scale factor used to map display coordinates to original image.

        Return:
            None
        """
        if event == cv2.EVENT_LBUTTONDOWN:
            if len(self.points) < 4:
                orig_x = int(x / param)
                orig_y = int(y / param)
                self.points.append((orig_x, orig_y))
                print(f"[INFO] Point {len(self.points)}: {orig_x}, {orig_y}")
            else:
                print("[INFO] Already 4 points. Press 'r' to reset.")
    
    @staticmethod
    def center_window(window_name: str, width: int, height: int):
        """Center an OpenCV window on screen.

        Args:
            window_name (str): OpenCV window name.
            width (int): Window width in pixels.
            height (int): Window height in pixels.

        Return:
            None
        """
        try:
            import subprocess
            output = subprocess.check_output(['xdpyinfo'], stderr=subprocess.DEVNULL).decode()
            for line in output.split('\n'):
                if 'dimensions:' in line:
                    dims = line.split()[1].split('x')
                    screen_w, screen_h = int(dims[0]), int(dims[1])
                    break
            else:
                screen_w, screen_h = 1920, 1080
        except Exception:
            screen_w, screen_h = 1920, 1080
        x = (screen_w - width) // 2
        y = (screen_h - height) // 2
        cv2.moveWindow(window_name, x, y)
    
    def calibrate(self, frame: np.ndarray = None):
        """Run interactive 4-point board calibration.

        Args:
            frame (np.ndarray, optional): Optional camera frame to calibrate from.

        Return:
            None
        """
        if frame is not None:
            # Use captured frame as calibration source.
            image = cv2.resize(frame, None, fx=self.scale, fy=self.scale)
            print("[INFO] Photo captured from camera")
        else:
            # Load calibration source from disk.
            orig_image = cv2.imread(self.image_path)
            image = cv2.resize(orig_image, None, fx=self.scale, fy=self.scale)
            print("[INFO] Image loaded from file")
        
        cv2.namedWindow("Calibration Plateau", cv2.WINDOW_NORMAL)
        
        h, w = image.shape[:2]
        self.center_window("Calibration Plateau", w, h)
        
        cv2.setMouseCallback("Calibration Plateau", self.mouse_click, param=self.scale)
        
        print("[INFO] Click on the 4 corners of the board (top-left, top-right, bottom-left, bottom-right)")
        print("[INFO] Press 'R' to reset or wait for the 4 points to be detected")
        
        first_display = True
        
        while True:
            vis = image.copy()
            
            # Draw selected corner points and labels.
            for idx, (ox, oy) in enumerate(self.points):
                x = int(ox * self.scale)
                y = int(oy * self.scale)
                cv2.circle(vis, (x, y), 6, (0, 0, 255), -1)
                cv2.circle(vis, (x, y), 8, (255, 255, 255), 2)  # White border
                cv2.putText(vis, str(idx+1), (x+8, y-8),
                            cv2.FONT_HERSHEY_SIMPLEX, 0.7, (0, 255, 0), 2)
            
            cv2.imshow("Calibration Plateau", vis)
            cv2.resizeWindow("Calibration Plateau", vis.shape[1], vis.shape[0])
            if first_display:
                print("[INFO] Photo displayed - waiting for clicks on corners")
                first_display = False
            
            key = cv2.waitKey(1) & 0xFF
            
            if key == ord('r'):
                print("[INFO] Resetting points")
                self.points = []
            elif key == ord('q'):
                print("[INFO] Calibration cancelled")
                cv2.destroyAllWindows()
                return
            
            if len(self.points) == 4:
                print("[INFO] 4 points detected ✓")
                break
        
        cv2.destroyAllWindows()
        print("[INFO] Calibration complétée")
        self.save_calibration()
    
    def save_calibration(self):
        """Save selected board-corner points to the calibration JSON file.

        Return:
            None
        """
        calibration_points = {
            "top_left": self.points[0],
            "top_right": self.points[1],
            "bottom_right": self.points[2],
            "bottom_left": self.points[3]
        }
        
        with open(self.calibration_file, 'w') as f:
            json.dump(calibration_points, f, indent=4)
        
        print("[INFO] Calibration saved to calibration_points.json")
    
    def load_calibration(self) -> dict:
        """Load board-corner calibration points from JSON.

        Return:
            dict: Calibration points dictionary.
        """
        with open(self.calibration_file, 'r') as f:
            return json.load(f)
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

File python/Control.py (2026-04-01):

# This files handle physical control of the game.

# It will take a chess move and transform it into physical actions and send it via serial bus

import numpy as np
import chess

# Here is all the object for a* pathfinding algorithm
class Position:
    """Represents a 2D position point with x and y coordinates."""
    x: float
    y: float

    def __init__(self, x: float, y: float):
        """Initialize position with x and y coordinates.
        
        Args:
            x (float): X coordinate value.
            y (float): Y coordinate value.
        
        Return:
            None
        """
        self.x = x
        self.y = y

    def __eq__(self, value):
        """Compare two positions for equality.
        
        Args:
            value (Position): Position to compare with.
        
        Return:
            bool: True if positions are equal, False otherwise.
        """
        return self.x == value.x and self.y == value.y

    def __hash__(self):
        """Return hash of position for use in sets/dicts during pathfinding.
        
        Args:
            None
        
        Return:
            int: Hash value of the position.
        """
        return hash((self.x, self.y))
    
class Command:
    """Represents a movement command with position and magnet state."""
    position: Position
    magnet_state: bool
    
    def __init__(self, position: Position = Position(0.0, 0.0), magnet_state: bool = False):
        """Initialize command with position and magnet state.
        
        Args:
            position (Position): Target position for movement.
            magnet_state (bool): Magnet state (True for on, False for off).
        
        Return:
            None
        """
        self.position = position
        self.magnet_state = magnet_state

class Node:
    """Represents a node in A* pathfinding grid with costs and neighbors."""
    position: Position
    gCost: float
    hCost: float
    fCost: float
    parent: 'Node'
    neighbors: list['Node']

    def __init__(self, position: Position = Position(0.0, 0.0)):
        """Initialize pathfinding node with position and costs.
        
        Args:
            position (Position): Node position on grid.
        
        Return:
            None
        """
        self.position = position
        self.gCost = 0.0
        self.hCost = 0.0
        self.fCost = 0.0
        self.parent = None
        self.neighbors = []

    def __eq__(self, value):
        """Compare nodes by position.
        
        Args:
            value (Node): Node to compare with.
        
        Return:
            bool: True if positions are equal, False otherwise.
        """
        return self.position == value.position

    def __hash__(self):
        """Return hash of node by position for set/dict storage.
        
        Args:
            None
        
        Return:
            int: Hash value of the node's position.
        """
        return hash(self.position)

class Grid:
    """A* pathfinding grid for motion planning on chess board."""
    nodes: list[list[Node]]
    width: int
    height: int
    obstacle_remove_position: Position

    def __init__(self, width: int, height: int):
        """Initialize A* pathfinding grid with nodes.
        
        Args:
            width (int): Grid width in squares.
            height (int): Grid height in squares.
        
        Return:
            None
        """
        self.obstacle_remove_position = Position(0.5, 5.5)  # Position to remove obstacle for captured pieces
        self.width = width * 2 + 1
        self.height = height * 2 + 1
        # Use half-step coordinates so intermediate nodes land between board squares
        self.nodes = [[Node(Position((x + 1) / 2, (y + 1) / 2)) for x in range(self.width)] for y in range(self.height)]
    
    def get_node(self, position: Position) -> Node:
        """Return node at given position, or None if out of bounds.
        
        Args:
            position (Position): Position to retrieve node from.
        
        Return:
            Node: Node at position, or None if invalid.
        """
        if position.x < 0.5 or position.x > self.width/2 or position.y < 0.5 or position.y > self.height/2:
            return None
        return self.nodes[int(position.y*2)-1][int(position.x*2)-1]
    
    def get_neighbors(self, node: Node) -> list[Node]:
        """Get neighboring nodes for pathfinding (4-directional or 8-directional).
        
        Args:
            node (Node): Node to get neighbors for.
        
        Return:
            list[Node]: List of valid neighboring nodes.
        """
        neighbors = []
        if (node.position.x % 1 == 0 and node.position.y % 1 != 0) or (node.position.x % 1 != 0 and node.position.y % 1 == 0):
            # direction without diagonals
            directions = [(-0.5, 0), (0.5, 0), (0, -0.5), (0, 0.5)]
        else:
            # direction with diagonals
            directions = [(-0.5, 0), (0.5, 0), (0, -0.5), (0, 0.5),
                        (-0.5, -0.5), (-0.5, 0.5), (0.5, -0.5), (0.5, 0.5)]

        for direction in directions:
            neighbor_x = node.position.x + direction[0]
            neighbor_y = node.position.y + direction[1]
            neighbor_node = self.get_node(Position(neighbor_x, neighbor_y))
            if neighbor_node is not None:
                neighbors.append(neighbor_node)

        return neighbors

    def initialize_links(self):
        """Set up neighbor relationships for all nodes in grid.
        
        Args:
            None
        
        Return:
            None
        """
        for i in range(self.height):
            for j in range(self.width):
                node = self.nodes[i][j]
                node.neighbors = self.get_neighbors(node)

    def add_obstacle(self, position: Position):
        """Add obstacle by removing all neighbors from node.
        
        Args:
            position (Position): Position to add obstacle at.
        
        Return:
            None
        """
        node = self.get_node(position)
        if node:
            node.neighbors = []  # Remove all neighbors to create an obstacle
    
    def remove_obstacle(self, position: Position):
        """Remove obstacle by restoring neighbors to node.
        
        Args:
            position (Position): Position to remove obstacle from.
        
        Return:
            None
        """
        node = self.get_node(position)
        if node:
            node.neighbors = self.get_neighbors(node)  # Restore neighbors to remove obstacle
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

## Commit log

2026-01-13 remise proposition de projet
2026-01-13 addition de library
2026-01-13 Mise à jour du README.md pour ajouter des instructions détaillées sur l'utilisation de PowerShell et le workflow Git recommandé
2026-01-14 kicad project and schematic added to repository
    [CNChess_KiCad.kicad_pcb, CNChess_KiCad.kicad_sch]
2026-01-15 remove print
2026-01-15 removed useless device
2026-01-15 start of ui remade the board -start of movement -docker file
2026-01-26 update kicad schematic
    [CNChess_KiCad.kicad_pcb, CNChess_KiCad.kicad_sch]
2026-01-27 remise tableau de bord 1
2026-01-27 First implementation of stepper control on esp32
2026-01-27 refactor command handling by removing CommandType enum and simplifying switch cases
2026-01-27 PCB tracks + remise tableau de bord 1
    [CNChess_KiCad.kicad_pcb, CNChess_KiCad.kicad_sch]
2026-01-28 removing piece is now working but it doesnt deactivate magnet between 2 path
2026-01-28 add new command class with magnet state
2026-01-28 ajout des modèles 3d et terminé V1 du PCB
    [BTT TMC2208 TMC2209 UART Stepper Driver.step, CNChess_KiCad.kicad_pcb, CNChess_KiCad.kicad_sch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]
2026-01-28 ajustement modeles 3d
    [CNChess_KiCad.kicad_pcb]
2026-01-28 start of refactor for esp32, not working right now and communication still to do
    [Control.py, main.cpp]
2026-01-30 start of homing and communication pretty much working
2026-02-02 Addition of servo control and working homing procedure
2026-02-02 addition of a condition for faster homing movement
2026-02-03 changed distance value for homing
2026-02-03 servo to move piece working
2026-02-03 update elec et TBsem5
    [CNChess_KiCad.kicad_pcb, CNChess_KiCad.kicad_sch, bom.csv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]
2026-02-03 Mask bleu et jaune camera
2026-02-03 fix edge case
2026-02-03 mapping de la grid
2026-02-03 pcb ready
    [CNChess_KiCad.kicad_pcb]
2026-02-03 fix diagonal path finding
    [Control.py, main.py]
2026-02-11 Test avec image importé. met point au milieu des cases
    [board-square-positions-demo.csv]
2026-02-11 dimension of board
2026-02-18 add grid for board
2026-02-18 working on real prototype
2026-02-18 give UCI for move with two different board position
    [board-square-positions-demo.csv]
2026-02-18 reste a coder controller da la settings page
2026-02-24 resign button
2026-02-24 start button fixed
2026-02-25 change servo top position
2026-02-25 fixed movement with pcb
    [main.cpp]
2026-03-08 timer are now working
2026-03-09 added draw dialog and fix bug with play again button in dialogs
2026-03-09 added spinning gear to waiting dialog
2026-03-11 fixed thread bug but waiting screen black when checkmate
    [CNChess.py]
2026-03-11 basic move detection working on real board
2026-03-11 fix calibration
2026-03-11 recalibrate servo motor and added button pin
2026-03-15 added evaluation function and start time button
2026-03-15 start of move back button
2026-03-18 remove unused file
    [board-square-positions-demo.csv]
2026-03-18 servo command added to access from settings
2026-03-18 prend info du board au lieu de la caméra avant move du joueur
2026-03-18 Add custom message handling for button press waiting state
2026-03-18 added camera to settings page
2026-03-20 now possible to control gantry with ui
2026-03-20 recalibration of servo and z working in ui
2026-03-25 invert row in cam to fit board
    [Cam.py]
2026-03-25 fixed turn indicator problem and added thread clean up
2026-03-25 added thread for home com
2026-03-25 fixed gear label
2026-03-25 try to fix thread program
2026-03-25 addition of 3 frame validation before sending move
2026-03-25 decrease to 0.1 sec between frame
2026-03-25 fixed problem with clock and slowed delay of cam
    [Cam.py]
2026-03-25 new process image is old preocess frame. no more old process image
2026-03-26 fix hanging thread (claude mvp)
    [Communication.py, main.py]
2026-03-27 made back button in settings page return to right page
2026-03-27 fixed going back button
2026-03-27 fixed problem with time when invalid move, made calibration possible with ui and added invalid move dialog
    [Cam.py]
2026-03-29 made image the size of button for difficulty
2026-04-01 fixed homing in settings page
2026-04-01 image is updating in setting page and fixed streching issue with move history
    [Cam.py]
2026-04-01 added escape button to quit application and F11 to full screen
2026-04-09 added promotion detection in camera and made message text bigger
2026-04-10 added time control and fix bug when not plugged into esp32
    [CNChess.py]
2026-04-15 small fix in code and changed docs directory for github pages
    [main.cpp]
2026-04-15 final update to project, fix camera image in settings page update
2026-04-15 All the parts of the board and chess pieces
2026-04-16 fixed weird nose and fix homing while waiting for button press
    [Communication.py, main.cpp]
